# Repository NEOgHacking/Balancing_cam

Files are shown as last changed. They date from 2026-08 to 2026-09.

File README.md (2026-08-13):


# Balancing_cam
This is a side project to improve on the balancing robot with a new smaller esd protected pcb to prevent failures on the board, also to make the board smaller and make room for a second battery pack.
# PCB

This is a small 50x50 PCB made in kicad, it uses the esp32s3 and tmc2209 stepper drivers.
# Specs
Using:
ESP32S3 mini 1
2x TMC2209 stepper drivers
LSM6DS3 IMU
2x battery pack of 2x 18650 cells so in total 4x 18650 cells
connectivity for rc reciever and VTX

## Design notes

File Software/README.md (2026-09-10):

This folder contains the software source files, written for an ESP32 using the Arduino framework. PlatformIO is used as environment, as it is very easy to use, and provides somewhat more advanced functions, compared to the very basic Arduino IDE. 

# Build environment
For setting up PlatformIO, see https://docs.platformio.org/en/latest/ide/vscode.html. 

Clone the repository. I strongly advice to not download the source files as a zip package, but to use Git properly. The code is very experimental, and will be often updated.

Once installed, go to PlatformIO home in the IDE. In there, click "Open Project", and navigate to the location where you cloned the repository. Select the "Software" folder, and then click "Open "Software"". 

Open src/main.cpp. You should now be able to combile (ctrl+alt+B).

# Uploading firmware
For uploading, I strongly prefer OTA, as this works very nice in PlatformIO.  

Beware: when using the A4988 driver, you have to specify a flag. When using any other driver, remove this flag. This is because the A4988 has a different microstepping selection table. 

## Serial port
For the first upload, you'll need to upload via USB / the serial port. In platformio.ini, state the COM port under which the ESP32 module is connected (uncomment the line with an IP address / host name), for example 
upload_port = COM3. 
; upload_port = balancingRobot.local

Hit the upload button. Currently, the auto reset functionality of the ESP32 module doesn't seem to work, see Issue #10. So, once the message "Serial port COMx" appears, press the enable and boot buttons on the module. First release the boot button, then the enable button. You might have to try a few times. Luckily, once succeeded with the serial upload, you can use OTA upload.

## OTA upload
When the ESP32 boots, it's IP address is printed. In platformio.ini, fill in this IP address under upload_port. Or, even better, use the hostname balancingRobot.local. This means you don't have to mess around with IP addresses. Make sure to be connected to the same WiFi network as the ESP32, and hit upload.

*Update*: in the ps3control branch, the ESP32 has insufficient flash memory to store the OTA upload. Hence, it is disabled in this branch. 

## File system
Initially, or when changing the web page files, you need to upload the file system. To do so, open a terminal within the PlatformIO environment, and run:
platformio run --target uploadfs

This will upload all content of the data folder to the ESP32 flash memory (either via the serial port or OTA).

# WiFi connection
After flashing, the ESP32 will start an access point (AP), named balancingRobot. The default key is "turboturbo". Once connected, open the balancingRobot web configuration page (index3.htm). Here, among others, you can change the WiFi options. Under "WiFi configuration", enter the SSID and key of your home network, change the selector from "AP" to "SSID", and click the "set" button, followed by the "reboot" button. If all goes well, the ESP32 will now connect to your home network. 

*Update:* I noticed that in the latest version, the web pages are not correctly loaded, when the ESP32 is running in access point mode. When connected to a known SSID, everything works as it should.
To configure the WiFi settings without a web page, we use the serial interface (115200 baud). 
The command structure is: \
a "w" for wireless related settings, followed by a "s" for SSID, "k" for key, and "m" for WiFi mode (0 = access point, 1 = connect to SSID), followed by the content, followed by a terminating "x". The recipe for connecting to a known SSID is thus:\
wsYOURSSIDx\
wkYOURKEYx\
wm1x\
Restart the ESP32, and it should connect to the known WiFi network ("wrx" will reset the ESP32).\
The serial interface will print information on whether the connection to a known SSID is successful. If the home network cannot be found, the AP will be started.

# Web page editor
hostName.local/edit

User/pass: admin, admin

Be aware though that changes here are not kept on your PC, so make sure to copy and paste everything.

# Plotting signals
hostName.local/plotTest.htm

To be merged into index.htm at some point

For this to work, first load plotTest.htm, then index.htm. This allows to view signals, while simultaneously adjusting parameters. 

# Wifi control
For a slider based web page to control your robot (this will also work in access point mode)

IPaddress/control.htm
hostName.local/control.htm
or, if you connect to the access point of the robot: 192.168.4.1/control.htm

# Bluetooth control
The ps3control branch supports a ps3 controller. This is convenient, as the ESP32 has bluetooth, and no additional hardware is required. 

To be documented, soon hopefully. Very short: use sixaxispairtool to assign the correct MAC address to the PS3 controller. The MAC address is printed over the serial interface, and is also visible in the web interface. 

The ps3control branch doesn't support OTA anymore, as flash space is limited on the ESP32. 

# MQTT dashboard
This branch also supports MQTT-based robot status publishing and command control.

## Robot firmware MQTT behavior
- The ESP32 connects to a WiFi network configured in preferences.
- It publishes status updates every second to `robots/<robotName>/status`.
- Each status message is JSON and includes:
  - `name`
  - `battery`
  - `angle`
  - `state`
- The robot subscribes to:
  - `robots/<robotName>/command`
  - `robots/all/command`
- Supported commands:
  - `stop` — disable control and stop the robot
  - `selfright` / `restart` — trigger a self-right attempt

## Running the PC dashboard
From the `Software` folder, install the Python dependency and start the GUI:

```bash
python3 -m pip install -r requirements.txt
python3 mqtt_dashboard.py
```

The dashboard will:
- discover available robots via `robots/+/status`
- display a status card for each robot
- show battery voltage, angle, and control state
- provide buttons for `Stop` and `Restart` per robot
- provide a global `Stop All Robots` button

## Broker configuration
The default broker is set to `broker.hivemq.com` on port `1883`.

### Using a local broker
For a local MQTT broker, install Mosquitto or another MQTT broker on your network machine.
- On Linux: `sudo apt install mosquitto`
- On macOS: `brew install mosquitto`

Then update the connection target:
- in `src/main.cpp`, change `kMqttBroker` to your broker IP or hostname, for example `"192.168.1.42"`
- in `mqtt_dashboard.py`, either edit `BROKER`/`PORT` or set environment variables:

```bash
export MQTT_BROKER=192.168.1.42
export MQTT_PORT=1883
python3 mqtt_dashboard.py
```

If the broker is running on the same PC as the dashboard, use `localhost` or `127.0.0.1`.

If the broker is on your local network, use the broker's LAN IP address so the ESP32 can reach it.

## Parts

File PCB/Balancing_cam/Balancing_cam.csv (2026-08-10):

Reference | Qty | Value | DNP | Exclude from BOM | Exclude from Board | Footprint | # | LCSC#
C1,C2,C3,C4,C8,C9,C10,C11,C12,C13,C17,C18,C19,C21,C24,C26,C29,C30,C31,C32,C34,C35,C37,C38 | 24 | 100n |  |  |  | Capacitor_SMD:C_0402_1005Metric | 1 | C307331
C5,C14 | 2 | 100μ |  |  |  | Capacitor_SMD:CP_Elec_6.3x5.4 | 2 | C2887272
C6,C15 | 2 | 2u2 |  |  |  | Capacitor_SMD:C_0603_1608Metric | 3 | C57895
C7,C16 | 2 | 22n |  |  |  | Capacitor_SMD:C_0402_1005Metric | 4 | C337699
C20,C25 | 2 | 10u |  |  |  | Capacitor_SMD:C_0603_1608Metric | 5 | C194427
C22 | 1 | 47u |  |  |  | Capacitor_SMD:C_0805_2012Metric | 6 | C19103846
C23,C28 | 2 | 33n |  |  |  | Capacitor_SMD:C_0402_1005Metric | 7 | C472437
C27 | 1 | 100u |  |  |  | Capacitor_SMD:C_1206_3216Metric | 8 | C380356
C33 | 1 | 22u |  |  |  | Capacitor_SMD:C_0603_1608Metric | 9 | C59461
C36 | 1 | 1u |  |  |  | Capacitor_SMD:C_0402_1005Metric | 10 | C14445
C39,C40,C41,C42,C43,C44,C45,C46 | 8 | 1n |  |  |  | Capacitor_SMD:C_0603_1608Metric | 11 | C153291
D1 | 1 | DSK24L |  |  |  | Diode_SMD:D_SOD-123F | 12 | C2939005
D2,D3,D6,D7,D8,D9 | 6 | BAV99W |  |  |  | Package_TO_SOT_SMD:SOT-23 | 13 | C7502727
D4,D5 | 2 | WS2812B-4020 |  |  |  | footprints:WS2812B-4020 | 14 | C965557
F1,F2 | 2 | Fuse |  |  |  | Fuse:Fuseholder_Littelfuse_Nano2_154x | 15 | C108518
J1,J2 | 2 | JST_PH |  |  |  | footprints:JST_PH_S2B-PH-SM4-TB_1x02-1MP_P2.00mm_Horizontal | 16 | C295747
J3 | 1 | USB_C_Receptacle_USB2.0_16P |  |  |  | Connector_USB:USB_C_Receptacle_GCT_USB4105-xx-A_16P_TopMnt_Horizontal | 17 | C165948
J4 | 1 | JST_XH |  |  |  | Connector_JST:JST_XH_B2B-XH-A_1x02_P2.50mm_Vertical | 18 | C158012
J5,J9 | 2 | Conn_01x04 |  |  |  | Connector_PinHeader_2.54mm:PinHeader_1x04_P2.54mm_Vertical | 19 | C7501262
J6,J7 | 2 | Conn_01x04 |  |  |  | Connector_JST:JST_XH_B4B-XH-A_1x04_P2.50mm_Vertical | 20 | C144395
J8 | 1 | Conn_01x03 |  |  |  | Connector_JST:JST_GH_BM03B-GHS-TBT_1x03-1MP_P1.25mm_Vertical | 21 | C160389
L1,L2 | 2 | 2u2 |  |  |  | Inductor_SMD:L_1210_3225Metric | 22 | C3222669
L3,L4,L5,L6,L7,L8,L9,L10,L11,L12,L13,L14 | 12 | BLM18KG121TN1D |  |  |  | Inductor_SMD:L_0603_1608Metric | 23 | C85831
Q1 | 1 | BC817 |  |  |  | Package_TO_SOT_SMD:SOT-23 | 24 | C52801
R1,R2,R3,R4 | 4 | 100m |  |  |  | Resistor_SMD:R_1206_3216Metric | 25 | C309528
R5 | 1 | 52k3 |  |  |  | Resistor_SMD:R_0402_1005Metric | 26 | C2998086
R6,R9,R13,R14,R20 | 5 | 10k |  |  |  | Resistor_SMD:R_0402_1005Metric | 27 | C2906861
R7 | 1 | 14k7 |  |  |  | Resistor_SMD:R_0402_1005Metric | 28 | C2929988
R8 | 1 | 30k9 |  |  |  | Resistor_SMD:R_0402_1005Metric | 29 | C2933086
R10,R11 | 2 | 5.1k |  |  |  | Resistor_SMD:R_0603_1608Metric | 30 | C105580
R12,R21 | 2 | 1k |  |  |  | Resistor_SMD:R_0402_1005Metric | 31 | C2906864
R15,R18,R19 | 3 | 0R |  |  |  | Resistor_SMD:R_0402_1005Metric | 32 | C2906858
R16,R17,R22,R23,R24,R25 | 6 | 100R |  |  |  | Resistor_SMD:R_0603_1608Metric | 33 | C105588
SW1 | 1 | SW_SPDT |  |  |  | footprints:SS12D10G5 | 34 | C7431054
SW2,SW3 | 2 | B3U-1000P |  |  |  | Button_Switch_SMD:SW_SPST_B3U-1000P | 35 | C231329
U1,U2 | 2 | TMC2209-LA |  |  |  | Package_DFN_QFN:VQFN-28-1EP_5x5mm_P0.5mm_EP3.7x3.7mm_ThermalVias | 36 | C2150710
U3,U4 | 2 | TPS62933 |  |  |  | Package_TO_SOT_SMD:SOT-583-8 | 37 | C3200405
U5 | 1 | USBLC6-2P6 |  |  |  | Package_TO_SOT_SMD:SOT-666 | 38 | C15999
U6 | 1 | LSM6DS3 |  |  |  | Package_LGA:LGA-14_3x2.5mm_P0.5mm_LayoutBorder3x4y | 39 | C967633
U7 | 1 | ESP32-S3-MINI-1 |  |  |  | RF_Module:ESP32-S2-MINI-1 | 40 | C2913206

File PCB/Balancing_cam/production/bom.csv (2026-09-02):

Designator | Footprint | Quantity | Value | LCSC Part #
C1_4, C1_3, C1_2, C1, C10_4, C10_3, C10_2, C10, C11_4, C11_3, C11_2, C11, C12_4, C12_3, C12_2, C12, C13_4, C13_3, C13_2, C13, C17_4, C17_3, C17_2, C17, C18_4, C18_3, C18_2, C18, C19_4, C19_3, C19_2, C19, C2_4, C2_3, C2_2, C2, C21_4, C21_3, C21_2, C21, C24_4, C24_3, C24_2, C24, C26_4, C26_3, C26_2, C26, C29_4, C29_3, C29_2, C29, C3_4, C3_3, C3_2, C3, C30_4, C30_3, C30_2, C30, C31_4, C31_3, C31_2, C31, C32_4, C32_3, C32_2, C32, C34_4, C34_3, C34_2, C34, C35_4, C35_3, C35_2, C35, C37_4, C37_3, C37_2, C37, C38_4, C38_3, C38_2, C38, C4_4, C4_3, C4_2, C4, C8_4, C8_3, C8_2, C8, C9_4, C9_3, C9_2, C9 | 0402 | 96 | 100n
C14_4, C14_3, C14_2, C14, C5_4, C5_3, C5_2, C5 | CP_Elec_6.3x5.4 | 8 | 100μ
C15_4, C15_3, C15_2, C15, C6_4, C6_3, C6_2, C6 | 0603 | 8 | 2u2
C16_4, C16_3, C16_2, C16, C7_4, C7_3, C7_2, C7 | 0402 | 8 | 22n
C20_4, C20_3, C20_2, C20, C25_4, C25_3, C25_2, C25 | 0603 | 8 | 10u
C22_4, C22_3, C22_2, C22 | 0805 | 4 | 47u
C23_4, C23_3, C23_2, C23, C28_4, C28_3, C28_2, C28 | 0402 | 8 | 33n
C27_4, C27_3, C27_2, C27 | 1206 | 4 | 100u
C33_4, C33_3, C33_2, C33 | 0603 | 4 | 22u
C36_4, C36_3, C36_2, C36 | 0402 | 4 | 1u
C39_4, C39_3, C39_2, C39, C40_4, C40_3, C40_2, C40, C41_4, C41_3, C41_2, C41, C42_4, C42_3, C42_2, C42, C43_4, C43_3, C43_2, C43, C44_4, C44_3, C44_2, C44, C45_4, C45_3, C45_2, C45, C46_4, C46_3, C46_2, C46 | 0603 | 32 | 1n
D1_4, D1_3, D1_2, D1 | D_SOD-123F | 4 | DSK24L
D2_4, D2_3, D2_2, D2, D3_4, D3_3, D3_2, D3, D6_4, D6_3, D6_2, D6, D7_4, D7_3, D7_2, D7, D8_4, D8_3, D8_2, D8, D9_4, D9_3, D9_2, D9 | SOT-23 | 24 | BAV99W
D4_4, D4_3, D4_2, D4, D5_4, D5_3, D5_2, D5 | WS2812B-4020 | 8 | WS2812B-4020
F1_4, F1_3, F1_2, F1, F2_4, F2_3, F2_2, F2 | Fuseholder_Littelfuse_Nano2_154x | 8 | Fuse
J1_4, J1_3, J1_2, J1, J2_4, J2_3, J2_2, J2 | JST_PH_S2B-PH-SM4-TB_1x02-1MP_P2.00mm_Horizontal | 8 | JST_PH
J3_4, J3_3, J3_2, J3 | USB_C_Receptacle_GCT_USB4105-xx-A_16P_TopMnt_Horizontal | 4 | USB_C_Receptacle_USB2.0_16P
J4_4, J4_3, J4_2, J4 | JST_XH_B2B-XH-A_1x02_P2.50mm_Vertical | 4 | JST_XH
J5_4, J5_3, J5_2, J5, J9_4, J9_3, J9_2, J9 | PinHeader_1x04_P2.54mm_Vertical | 8 | Conn_01x04
J6_4, J6_3, J6_2, J6, J7_4, J7_3, J7_2, J7 | JST_XH_B4B-XH-A_1x04_P2.50mm_Vertical | 8 | Conn_01x04
J8_4, J8_3, J8_2, J8 | JST_GH_BM03B-GHS-TBT_1x03-1MP_P1.25mm_Vertical | 4 | Conn_01x03
L1_4, L1_3, L1_2, L1, L2_4, L2_3, L2_2, L2 | 1210 | 8 | 2u2
L10_4, L10_3, L10_2, L10, L11_4, L11_3, L11_2, L11, L12_4, L12_3, L12_2, L12, L13_4, L13_3, L13_2, L13, L14_4, L14_3, L14_2, L14, L3_4, L3_3, L3_2, L3, L4_4, L4_3, L4_2, L4, L5_4, L5_3, L5_2, L5, L6_4, L6_3, L6_2, L6, L7_4, L7_3, L7_2, L7, L8_4, L8_3, L8_2, L8, L9_4, L9_3, L9_2, L9 | 0603 | 48 | BLM18KG121TN1D
Q1_4, Q1_3, Q1_2, Q1 | SOT-23 | 4 | BC817
R1_4, R1_3, R1_2, R1, R2_4, R2_3, R2_2, R2, R3_4, R3_3, R3_2, R3, R4_4, R4_3, R4_2, R4 | 1206 | 16 | 100m
R10_4, R10_3, R10_2, R10, R11_4, R11_3, R11_2, R11 | 0603 | 8 | 5.1k
R12_4, R12_3, R12_2, R12, R21_4, R21_3, R21_2, R21 | 0402 | 8 | 1k
R13_4, R13_3, R13_2, R13, R14_4, R14_3, R14_2, R14, R20_4, R20_3, R20_2, R20, R6_4, R6_3, R6_2, R6, R9_4, R9_3, R9_2, R9 | 0402 | 20 | 10k
R15_4, R15_3, R15_2, R15, R18_4, R18_3, R18_2, R18, R19_4, R19_3, R19_2, R19 | 0402 | 12 | 0R
R16_4, R16_3, R16_2, R16, R17_4, R17_3, R17_2, R17, R22_4, R22_3, R22_2, R22, R23_4, R23_3, R23_2, R23, R24_4, R24_3, R24_2, R24, R25_4, R25_3, R25_2, R25 | 0603 | 24 | 100R
R5_4, R5_3, R5_2, R5 | 0402 | 4 | 52k3
R7_4, R7_3, R7_2, R7 | 0402 | 4 | 14k7
R8_4, R8_3, R8_2, R8 | 0402 | 4 | 30k9
SW1_4, SW1_3, SW1_2, SW1 | SS12D10G5 | 4 | SW_SPDT
SW2_4, SW2_3, SW2_2, SW2, SW3_4, SW3_3, SW3_2, SW3 | SW_SPST_B3U-1000P | 8 | B3U-1000P
TP1_4, TP1_3, TP1_2, TP1, TP10_4, TP10_3, TP10_2, TP10, TP11_4, TP11_3, TP11_2, TP11, TP12_4, TP12_3, TP12_2, TP12, TP13_4, TP13_3, TP13_2, TP13, TP14_4, TP14_3, TP14_2, TP14, TP15_4, TP15_3, TP15_2, TP15, TP16_4, TP16_3, TP16_2, TP16, TP17_4, TP17_3, TP17_2, TP17, TP18_4, TP18_3, TP18_2, TP18, TP19_4, TP19_3, TP19_2, TP19, TP2_4, TP2_3, TP2_2, TP2, TP21_4, TP21_3, TP21_2, TP21, TP22_4, TP22_3, TP22_2, TP22, TP23_4, TP23_3, TP23_2, TP23, TP3_4, TP3_3, TP3_2, TP3, TP4_4, TP4_3, TP4_2, TP4, TP5_4, TP5_3, TP5_2, TP5, TP6_4, TP6_3, TP6_2, TP6, TP7_4, TP7_3, TP7_2, TP7, TP8_4, TP8_3, TP8_2, TP8, TP9_4, TP9_3, TP9_2, TP9 | TestPoint_Pad_D1.5mm | 88 | TestPoint
U1_4, U1_3, U1_2, U1, U2_4, U2_3, U2_2, U2 | VQFN-28-1EP_5x5mm_P0.5mm_EP3.7x3.7mm_ThermalVias | 8 | TMC2209-LA
U3_4, U3_3, U3_2, U3, U4_4, U4_3, U4_2, U4 | SOT-583-8 | 8 | TPS62933
U5_4, U5_3, U5_2, U5 | SOT-666 | 4 | USBLC6-2P6
U6_4, U6_3, U6_2, U6 | LGA-14_3x2.5mm_P0.5mm_LayoutBorder3x4y | 4 | LSM6DS3
U7_4, U7_3, U7_2, U7 | ESP32-S2-MINI-1 | 4 | ESP32-S3-MINI-1

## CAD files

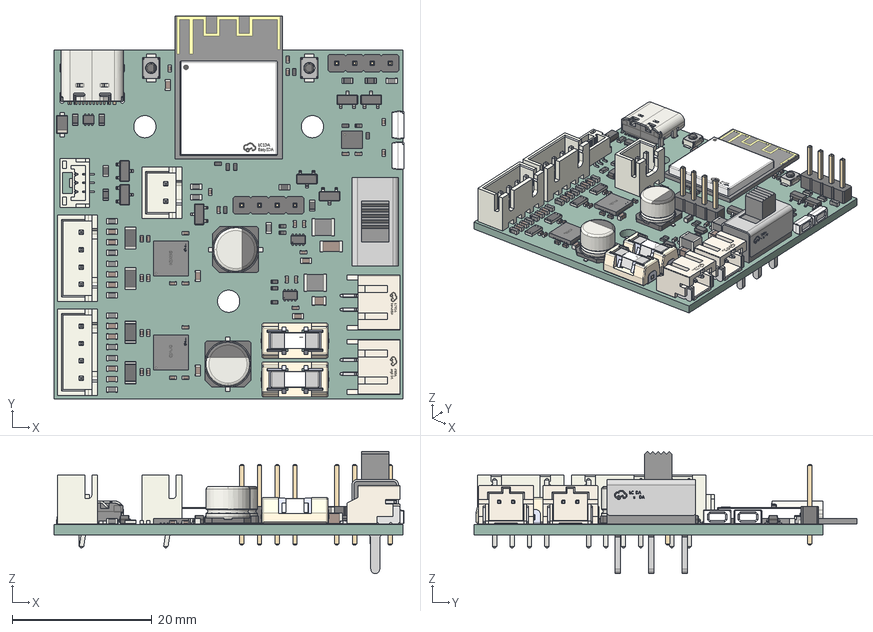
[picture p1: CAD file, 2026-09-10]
PCB/Balancing_cam/Balancing_cam.step
50.1 x 54.9 x 17.5 mm
C_0603_1608Metric x 13
R_1206_3216Metric x 4
CONN-SMD_P2.00_S2B-PH-SM4-TB-LF-SN x 2
C_0402_1005Metric x 29
R_0603_1608Metric x 8
R_0402_1005Metric x 13
D_SOD_123F
L_0603_1608Metric x 12
JST_B4B_XH_A x 2
BULETM-SMD_ESP32-S3-MINI-1-N8
SOT-583-8 x 2
SW_SPST_B3U-1000P x 2
PinHeader_1x04_P254mm_Vertical x 2
SOT-23 x 7
TQFN-28_L5.0-W5.0-H0.8-P0.50 x 2
CP_Elec_63x54 x 2
SW-TH_SHOU-HAN_SS12D10G4
LED-SMD_WS2812B-4020 x 2
L_1210_3225Metric x 2
¼þ1 x 2
¼þ2 x 4
µ艝 x 2
C_1206_3216Metric
USB_C_Receptacle_16P_TopMnt_Horizontal_GCT_USB4105-xx-A
SOT_666
JST_BM03B_GHS_TBT
LGA_14_3x25mm_P05mm_LayoutBorder3x4y
JST_B2B_XH_A
C_0805_2012Metric
Balancing_cam_PCB

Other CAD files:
Balancing_cam.blend

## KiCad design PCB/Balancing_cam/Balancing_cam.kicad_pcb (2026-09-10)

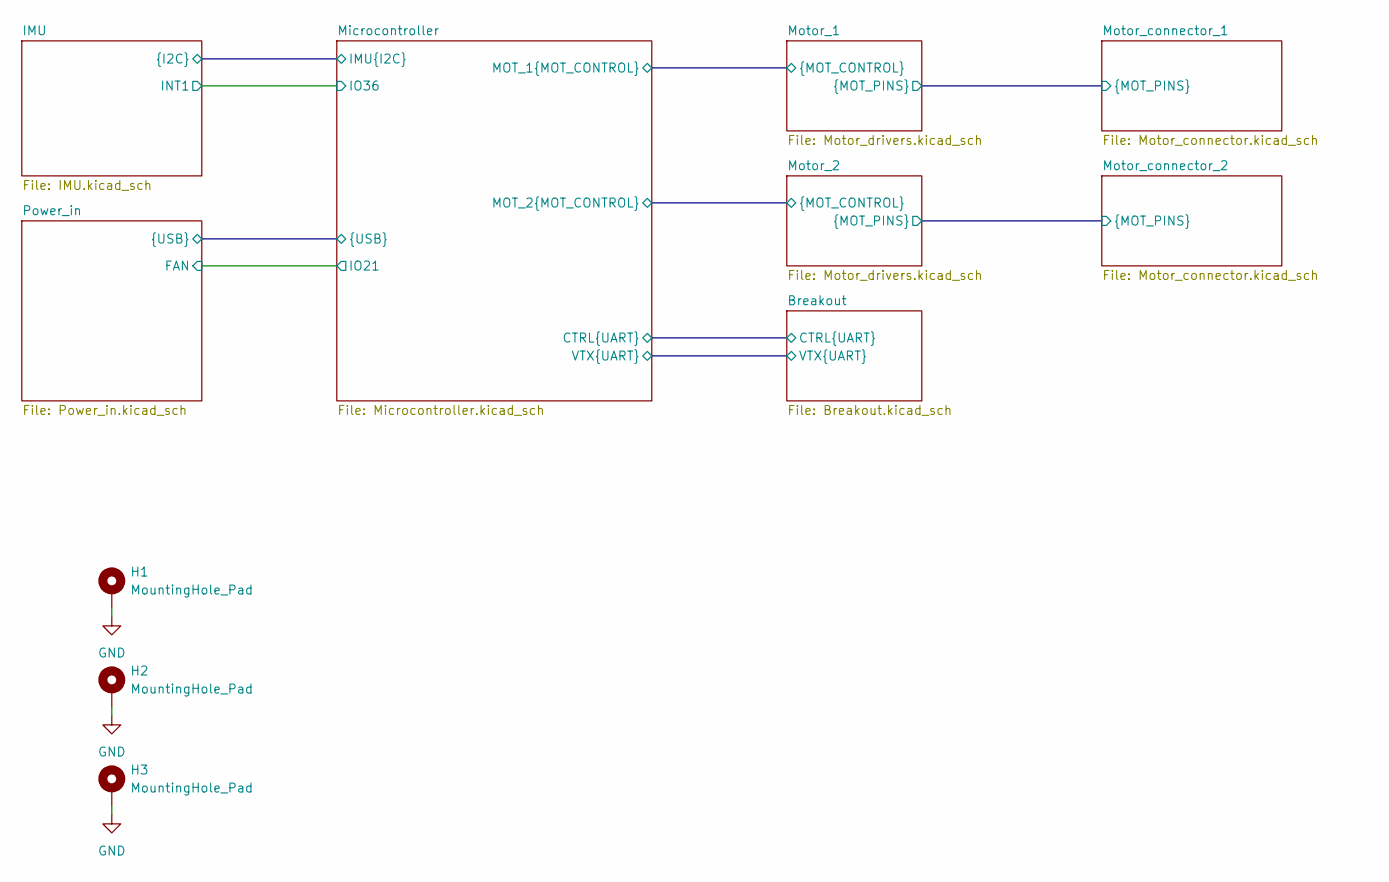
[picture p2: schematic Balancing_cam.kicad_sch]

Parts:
H1, H2, H3: MountingHole_Pad; MountingHole_3.2mm_M3_Pad

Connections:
GND: H1.1 (1_1), H2.1 (1_1), H3.1 (1_1); also elsewhere on the board

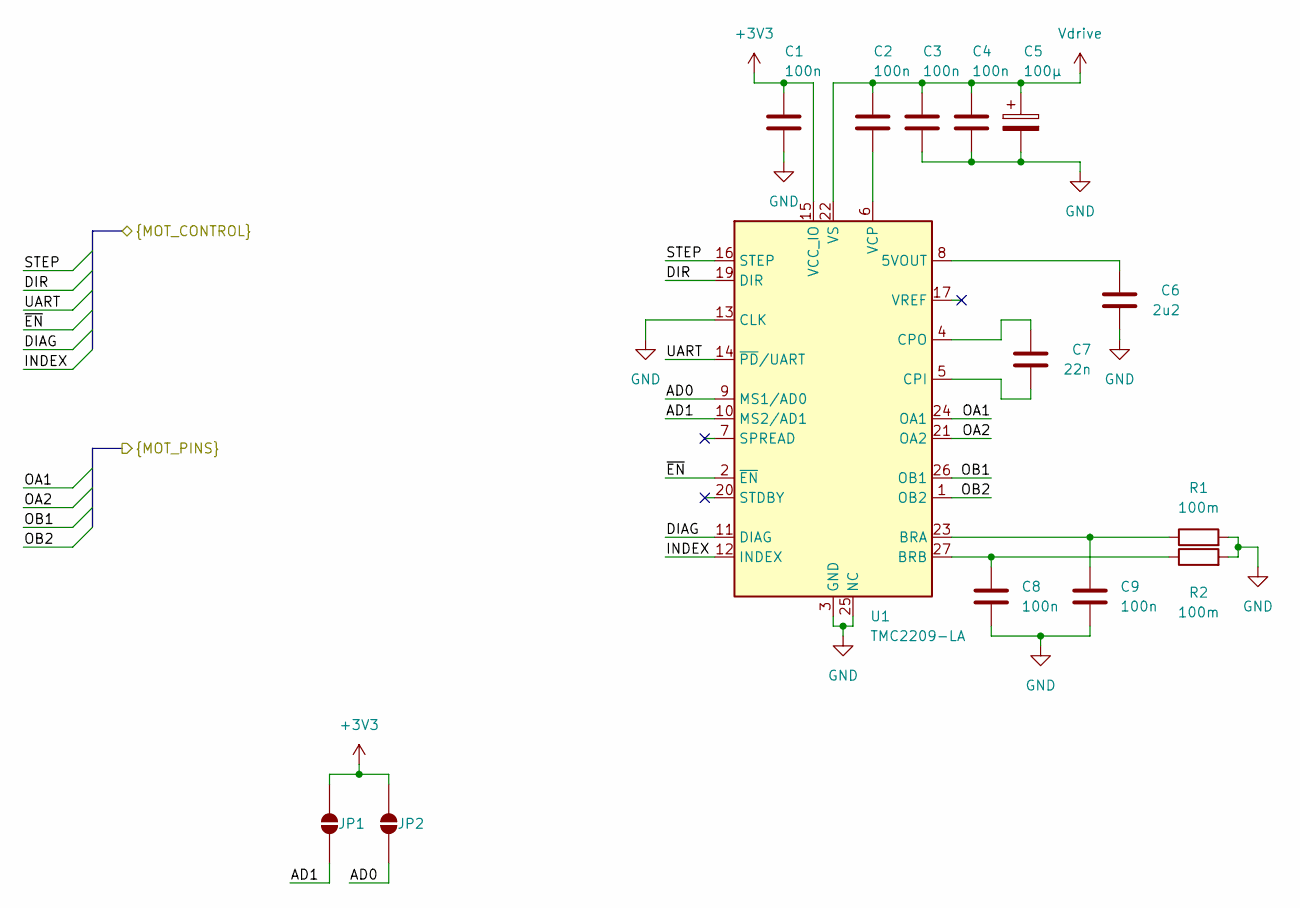
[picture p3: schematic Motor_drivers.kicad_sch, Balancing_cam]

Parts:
C1, C2, C3, C4, C8, C9: 100n; C_0402_1005Metric; LCSC# C307331
C5: 100μ; CP_Elec_6.3x5.4; LCSC# C2887272
C6: 2u2; C_0603_1608Metric; LCSC# C57895
C7: 22n; C_0402_1005Metric; LCSC# C337699
JP1, JP2: SolderJumper_2_Open; SolderJumper-2_P1.3mm_Open_RoundedPad1.0x1.5mm
R1, R2: 100m; R_1206_3216Metric; LCSC# C309528
U1: TMC2209-LA; VQFN-28-1EP_5x5mm_P0.5mm_EP3.7x3.7mm_ThermalVias; LCSC# C2150710

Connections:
+3V3: C1.2, JP1.1 (A), JP2.1 (A), U1.15 (VCC_IO); also elsewhere on the board
/Microcontroller/MOT_1.DIAG: U1.11 (DIAG); also elsewhere on the board
/Microcontroller/MOT_1.DIR: U1.19 (DIR); also elsewhere on the board
/Microcontroller/MOT_1.INDEX: U1.12 (INDEX); also elsewhere on the board
/Microcontroller/MOT_1.STEP: U1.16 (STEP); also elsewhere on the board
/Microcontroller/MOT_1.UART: U1.14 (~PD/UART); also elsewhere on the board
/Microcontroller/MOT_1.~EN: U1.2 (~EN); also elsewhere on the board
/Motor_1/AD0: JP2.2 (B), U1.9 (MS1/AD0)
/Motor_1/AD1: JP1.2 (B), U1.10 (MS2/AD1)
/Motor_1/OA1: U1.24 (OA1); also elsewhere on the board
/Motor_1/OA2: U1.21 (OA2); also elsewhere on the board
/Motor_1/OB1: U1.26 (OB1); also elsewhere on the board
/Motor_1/OB2: U1.1 (OB2); also elsewhere on the board
GND: C1.1, C3.1, C4.1, C5.2, C6.1, C8.2, C9.2, R1.2, R2.2, U1.3 (GND), U1.13 (CLK), U1.18 (GND), U1.25 (NC), U1.29 (GND); also elsewhere on the board
unnamed: C6.2, U1.8 (5VOUT)
unnamed: C9.1, R1.1, U1.23 (BRA)
unnamed: C8.1, R2.1, U1.27 (BRB)
unnamed: C7.1, U1.5 (CPI)
unnamed: C7.2, U1.4 (CPO)
unnamed: C2.1, U1.6 (VCP)
Vdrive: C2.2, C3.2, C4.2, C5.1, U1.22 (VS), U1.28 (VS); also elsewhere on the board

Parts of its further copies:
C10, C11, C12, C13, C17, C18: 100n; C_0402_1005Metric; LCSC# C307331
C14: 100μ; CP_Elec_6.3x5.4; LCSC# C2887272
C15: 2u2; C_0603_1608Metric; LCSC# C57895
C16: 22n; C_0402_1005Metric; LCSC# C337699
JP3, JP4: SolderJumper_2_Open; SolderJumper-2_P1.3mm_Open_RoundedPad1.0x1.5mm
R3, R4: 100m; R_1206_3216Metric; LCSC# C309528
U2: TMC2209-LA; VQFN-28-1EP_5x5mm_P0.5mm_EP3.7x3.7mm_ThermalVias; LCSC# C2150710

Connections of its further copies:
+3V3: C10.2, JP3.1 (A), JP4.1 (A), U2.15 (VCC_IO); also elsewhere on the board
/Microcontroller/MOT_1.UART: U2.14 (~PD/UART); also elsewhere on the board
/Microcontroller/MOT_2.DIAG: U2.11 (DIAG); also elsewhere on the board
/Microcontroller/MOT_2.DIR: U2.19 (DIR); also elsewhere on the board
/Microcontroller/MOT_2.INDEX: U2.12 (INDEX); also elsewhere on the board
/Microcontroller/MOT_2.STEP: U2.16 (STEP); also elsewhere on the board
/Microcontroller/MOT_2.~EN: U2.2 (~EN); also elsewhere on the board
/Motor_2/AD0: JP4.2 (B), U2.9 (MS1/AD0)
/Motor_2/AD1: JP3.2 (B), U2.10 (MS2/AD1)
/Motor_2/OA1: U2.24 (OA1); also elsewhere on the board
/Motor_2/OA2: U2.21 (OA2); also elsewhere on the board
/Motor_2/OB1: U2.26 (OB1); also elsewhere on the board
/Motor_2/OB2: U2.1 (OB2); also elsewhere on the board
GND: C10.1, C12.1, C13.1, C14.2, C15.1, C17.2, C18.2, R3.2, R4.2, U2.3 (GND), U2.13 (CLK), U2.18 (GND), U2.25 (NC), U2.29 (GND); also elsewhere on the board
unnamed: C15.2, U2.8 (5VOUT)
unnamed: C18.1, R3.1, U2.23 (BRA)
unnamed: C17.1, R4.1, U2.27 (BRB)
unnamed: C16.1, U2.5 (CPI)
unnamed: C16.2, U2.4 (CPO)
unnamed: C11.1, U2.6 (VCP)
Vdrive: C11.2, C12.2, C13.2, C14.1, U2.22 (VS), U2.28 (VS); also elsewhere on the board

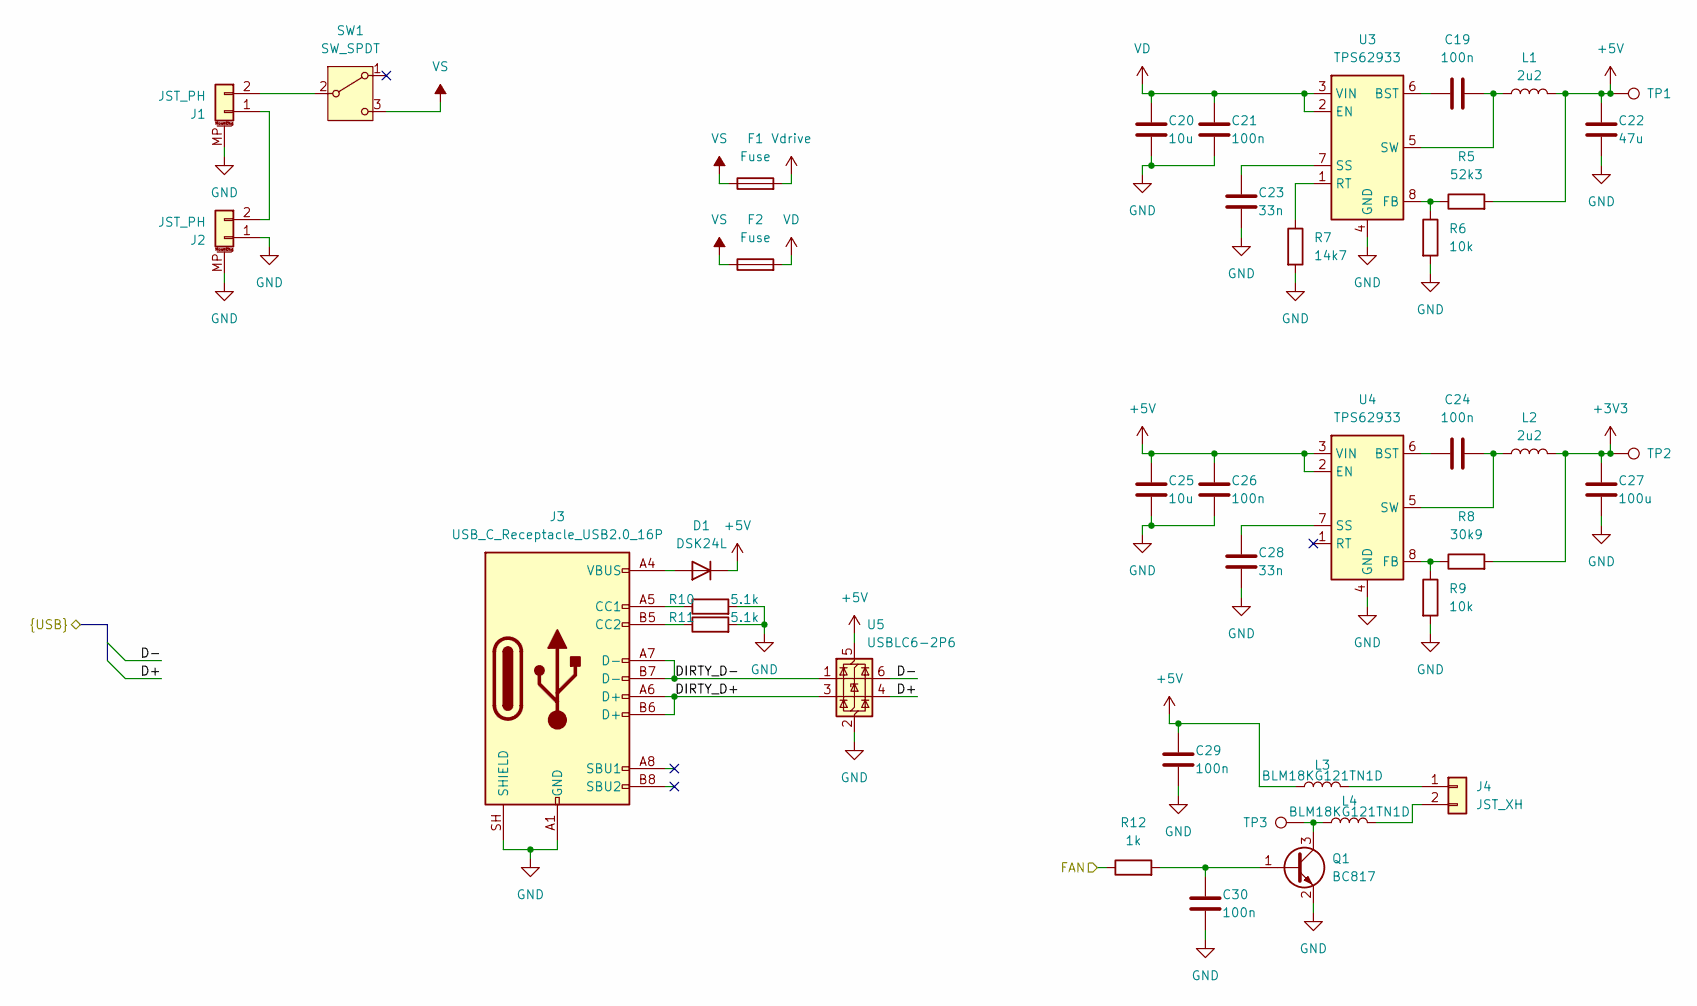
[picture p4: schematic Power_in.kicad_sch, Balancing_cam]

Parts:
C19, C21, C24, C26, C29, C30: 100n; C_0402_1005Metric; LCSC# C307331
C20, C25: 10u; C_0603_1608Metric; LCSC# C194427
C22: 47u; C_0805_2012Metric; LCSC# C19103846
C23, C28: 33n; C_0402_1005Metric; LCSC# C472437
C27: 100u; C_1206_3216Metric; LCSC# C380356
D1: DSK24L; D_SOD-123F; LCSC# C2939005
F1, F2: Fuse; Fuseholder_Littelfuse_Nano2_154x; LCSC# C108518
J1, J2: JST_PH; JST_PH_S2B-PH-SM4-TB_1x02-1MP_P2.00mm_Horizontal; LCSC# C295747
J3: USB_C_Receptacle_USB2.0_16P; USB_C_Receptacle_GCT_USB4105-xx-A_16P_TopMnt_Horizontal; LCSC# C165948
J4: JST_XH; JST_XH_B2B-XH-A_1x02_P2.50mm_Vertical; LCSC# C158012
L1, L2: 2u2; L_1210_3225Metric; LCSC# C3222669
L3, L4: BLM18KG121TN1D; L_0603_1608Metric; LCSC# C85831
Q1: BC817; SOT-23; LCSC# C52801
R5: 52k3; R_0402_1005Metric; LCSC# C2998086
R6, R9: 10k; R_0402_1005Metric; LCSC# C2906861
R7: 14k7; R_0402_1005Metric; LCSC# C2929988
R8: 30k9; R_0402_1005Metric; LCSC# C2933086
R10, R11: 5.1k; R_0603_1608Metric; LCSC# C105580
R12: 1k; R_0402_1005Metric; LCSC# C2906864
SW1: SW_SPDT; SS12D10G5; LCSC# C7431054
TP1, TP2, TP3: TestPoint; TestPoint_Pad_D1.5mm
U3, U4: TPS62933; SOT-583-8; LCSC# C3200405
U5: USBLC6-2P6; SOT-666; LCSC# C15999

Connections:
+3V3: C27.1, L2.2, R8.2, TP2.1 (1_1); also elsewhere on the board
+5V: C22.1, C25.1, C26.1, C29.1, D1.1 (K), L1.2, L3.1, R5.2, TP1.1 (1_1), U4.2 (EN), U4.3 (VIN), U5.5 (VBUS); also elsewhere on the board
/Microcontroller/D+: U5.4 (I/O2); also elsewhere on the board
/Microcontroller/D-: U5.6 (I/O1); also elsewhere on the board
/Microcontroller/IO21: R12.1; also elsewhere on the board
/Power_in/DIRTY_D+: J3.A6 (D+), J3.B6 (D+), U5.3 (I/O2)
/Power_in/DIRTY_D-: J3.A7 (D-), J3.B7 (D-), U5.1 (I/O1)
GND: C20.2, C21.2, C22.2, C23.2, C25.2, C26.2, C27.2, C28.2, C29.2, C30.2, J1.MP (MountPin), J2.1 (Pin_2), J2.MP (MountPin), J3.A1 (GND), J3.A12 (GND), J3.B1 (GND), J3.B12 (GND), J3.SH (SHIELD), Q1.2 (E), R6.2, R7.2, R9.2, R10.2, R11.2, U3.4 (GND), U4.4 (GND), U5.2 (GND); also elsewhere on the board
unnamed: D1.2 (A), J3.A4 (VBUS), J3.A9 (VBUS), J3.B4 (VBUS), J3.B9 (VBUS)
unnamed: J1.2 (Pin_1), SW1.2 (B)
unnamed: J1.1 (Pin_2), J2.2 (Pin_1)
unnamed: J3.A5 (CC1), R10.1
unnamed: J3.B5 (CC2), R11.1
unnamed: J4.1, L3.2
unnamed: J4.2, L4.2
unnamed: C30.1, Q1.1 (B), R12.2
unnamed: L4.1, Q1.3 (C), TP3.1 (1_1)
unnamed: C19.1, U3.6 (BST)
unnamed: R5.1, R6.1, U3.8 (FB)
unnamed: R7.1, U3.1 (RT)
unnamed: C23.1, U3.7 (SS)
unnamed: C19.2, L1.1, U3.5 (SW)
unnamed: C24.1, U4.6 (BST)
unnamed: R8.1, R9.1, U4.8 (FB)
unnamed: C28.1, U4.7 (SS)
unnamed: C24.2, L2.1, U4.5 (SW)
VD: C20.1, C21.1, F2.2, U3.2 (EN), U3.3 (VIN)
VS: F1.1, F2.1, SW1.3 (C)
Vdrive: F1.2; also elsewhere on the board

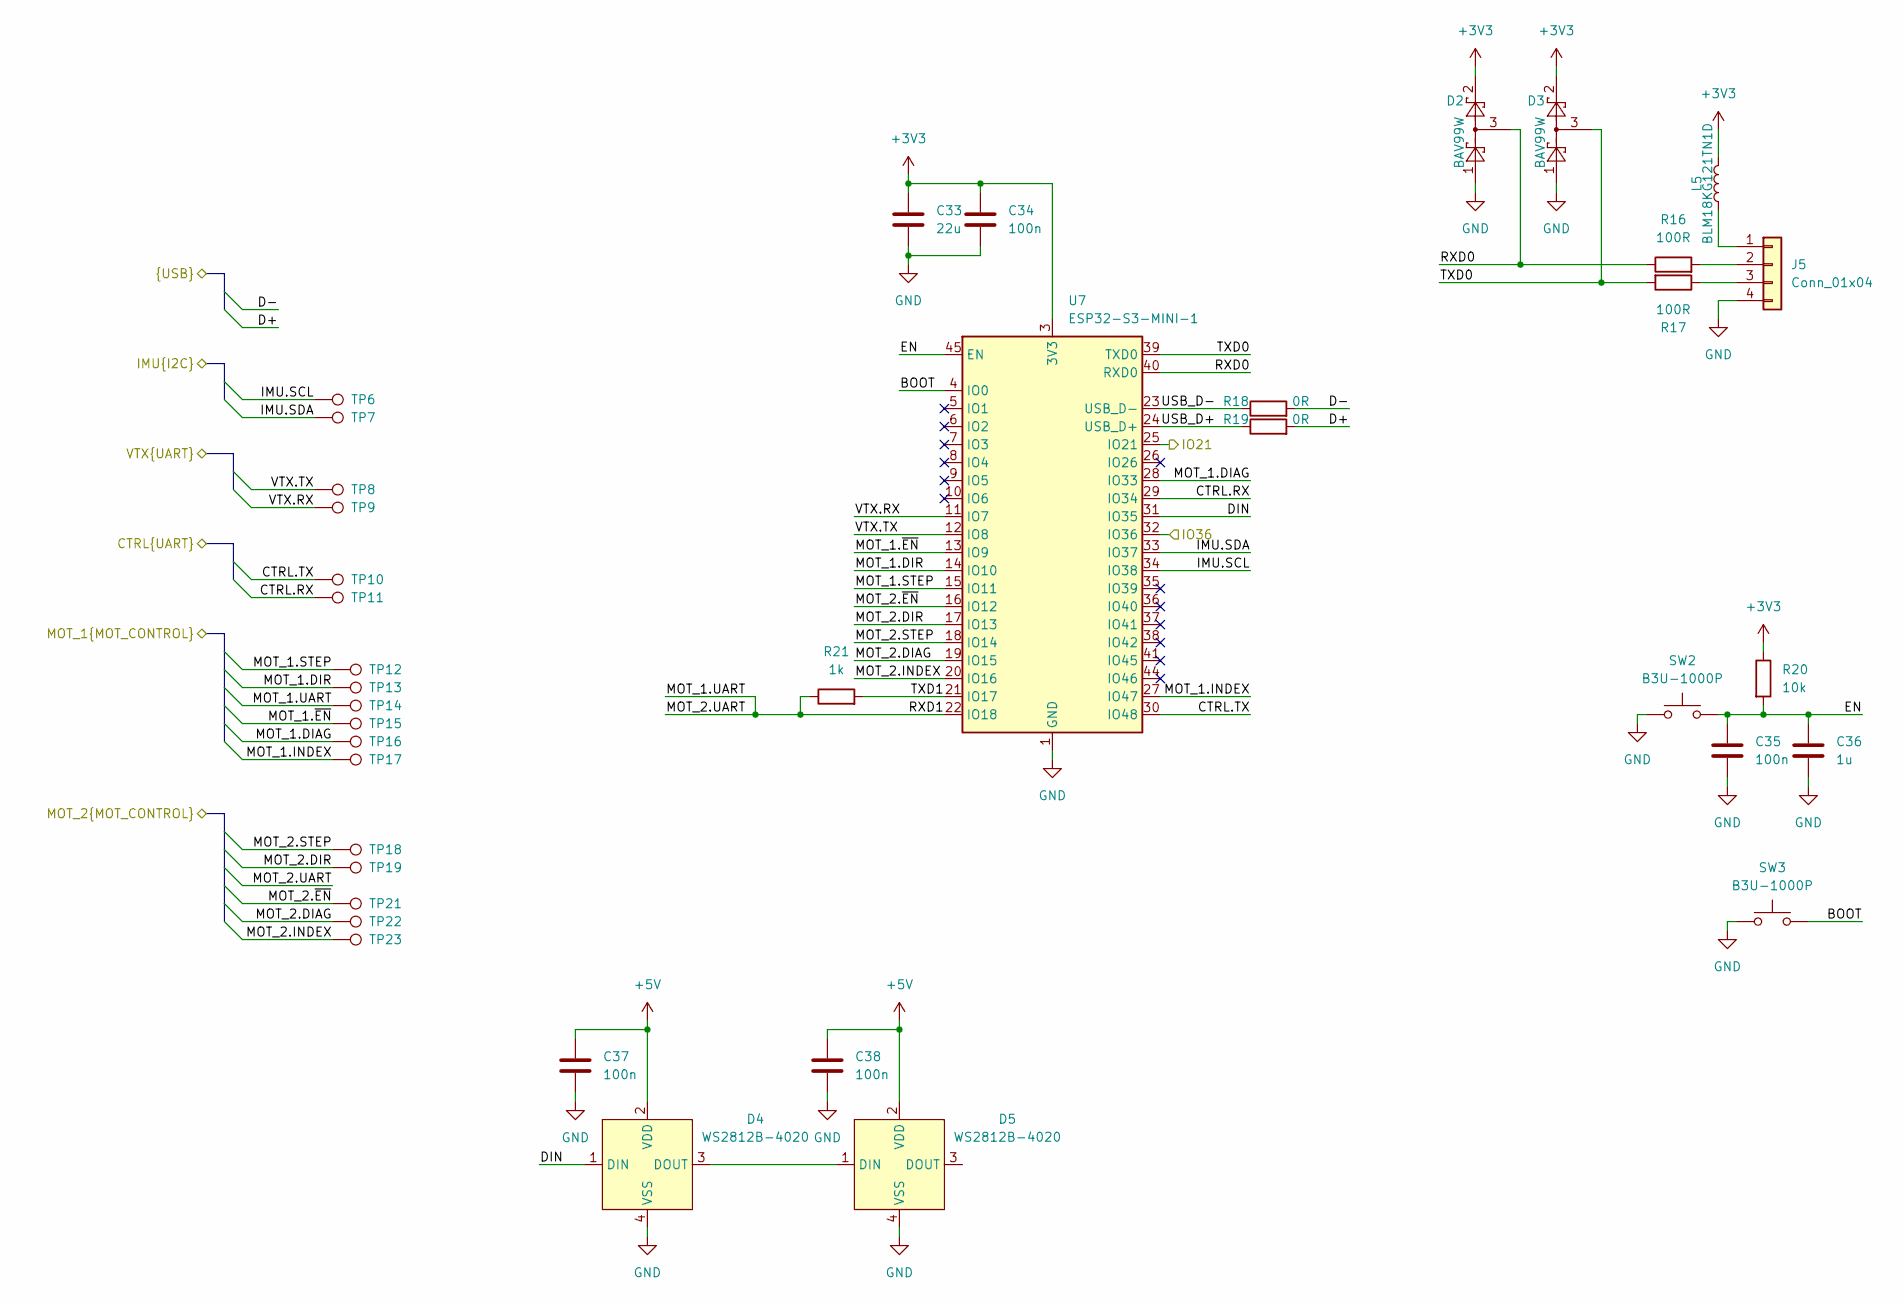
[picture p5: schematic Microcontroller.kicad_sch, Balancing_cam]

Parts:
C33: 22u; C_0603_1608Metric; LCSC# C59461
C34, C35, C37, C38: 100n; C_0402_1005Metric; LCSC# C307331
C36: 1u; C_0402_1005Metric; LCSC# C14445
D2, D3: BAV99W; SOT-23; LCSC# C7502727
D4, D5: WS2812B-4020; LCSC# C965557
J5: Conn_01x04; PinHeader_1x04_P2.54mm_Vertical; LCSC# C7501262
L5: BLM18KG121TN1D; L_0603_1608Metric; LCSC# C85831
R16, R17: 100R; R_0603_1608Metric; LCSC# C105588
R18, R19: 0R; R_0402_1005Metric; LCSC# C2906858
R20: 10k; R_0402_1005Metric; LCSC# C2906861
R21: 1k; R_0402_1005Metric; LCSC# C2906864
SW2, SW3: B3U-1000P; SW_SPST_B3U-1000P; LCSC# C231329
TP6, TP7, TP8, TP9, TP10, TP11, TP12, TP13, TP14, TP15, TP16, TP17, TP18, TP19, TP21, TP22, TP23: TestPoint; TestPoint_Pad_D1.5mm
U7: ESP32-S3-MINI-1; ESP32-S2-MINI-1; LCSC# C2913206

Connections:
+3V3: C33.1, C34.1, D2.2, D3.2, L5.2, R20.1, U7.3 (3V3); also elsewhere on the board
+5V: C37.1, C38.1, D4.2 (VDD), D5.2 (VDD); also elsewhere on the board
/Breakout/CTRL.RX: TP11.1 (1_1), U7.29 (IO34); also elsewhere on the board
/Breakout/CTRL.TX: TP10.1 (1_1), U7.30 (IO48); also elsewhere on the board
/Breakout/VTX.RX: TP9.1 (1_1), U7.11 (IO7); also elsewhere on the board
/Breakout/VTX.TX: TP8.1 (1_1), U7.12 (IO8); also elsewhere on the board
/IMU/INT1: U7.32 (IO36); also elsewhere on the board
/IMU/SCL: TP6.1 (1_1), U7.34 (IO38); also elsewhere on the board
/IMU/SDA: TP7.1 (1_1), U7.33 (IO37); also elsewhere on the board
/Microcontroller/BOOT: SW3.2, U7.4 (IO0)
/Microcontroller/D+: R19.2; also elsewhere on the board
/Microcontroller/D-: R18.2; also elsewhere on the board
/Microcontroller/DIN: D4.1 (DIN), U7.31 (IO35)
/Microcontroller/EN: C35.1, C36.1, R20.2, SW2.2, U7.45 (EN)
/Microcontroller/IO21: U7.25 (IO21); also elsewhere on the board
/Microcontroller/MOT_1.DIAG: TP16.1 (1_1), U7.28 (IO33); also elsewhere on the board
/Microcontroller/MOT_1.DIR: TP13.1 (1_1), U7.14 (IO10); also elsewhere on the board
/Microcontroller/MOT_1.INDEX: TP17.1 (1_1), U7.27 (IO47); also elsewhere on the board
/Microcontroller/MOT_1.STEP: TP12.1 (1_1), U7.15 (IO11); also elsewhere on the board
/Microcontroller/MOT_1.UART: R21.1, TP14.1 (1_1), U7.22 (IO18); also elsewhere on the board
/Microcontroller/MOT_1.~EN: TP15.1 (1_1), U7.13 (IO9); also elsewhere on the board
/Microcontroller/MOT_2.DIAG: TP22.1 (1_1), U7.19 (IO15); also elsewhere on the board
/Microcontroller/MOT_2.DIR: TP19.1 (1_1), U7.17 (IO13); also elsewhere on the board
/Microcontroller/MOT_2.INDEX: TP23.1 (1_1), U7.20 (IO16); also elsewhere on the board
/Microcontroller/MOT_2.STEP: TP18.1 (1_1), U7.18 (IO14); also elsewhere on the board
/Microcontroller/MOT_2.~EN: TP21.1 (1_1), U7.16 (IO12); also elsewhere on the board
/Microcontroller/RXD0: D2.3, R16.1, U7.40 (RXD0)
/Microcontroller/TXD0: D3.3, R17.2, U7.39 (TXD0)
/Microcontroller/TXD1: R21.2, U7.21 (IO17)
/Microcontroller/USB_D+: R19.1, U7.24 (USB_D+)
/Microcontroller/USB_D-: R18.1, U7.23 (USB_D-)
GND: C33.2, C34.2, C35.2, C36.2, C37.2, C38.2, D2.1, D3.1, D4.4 (VSS), D5.4 (VSS), J5.4, SW2.1, SW3.1, U7.1 (GND), U7.2 (GND), U7.42 (GND), U7.43 (GND), U7.46 (GND), U7.47 (GND), U7.48 (GND), U7.49 (GND), U7.50 (GND), U7.51 (GND), U7.52 (GND), U7.53 (GND), U7.54 (GND), U7.55 (GND), U7.56 (GND), U7.57 (GND), U7.58 (GND), U7.59 (GND), U7.60 (GND), U7.61 (GND), U7.62 (GND), U7.63 (GND), U7.64 (GND), U7.65 (GND); also elsewhere on the board
unnamed: D4.3 (DOUT), D5.1 (DIN)
unnamed: J5.1, L5.1
unnamed: J5.2, R16.2
unnamed: J5.3, R17.1

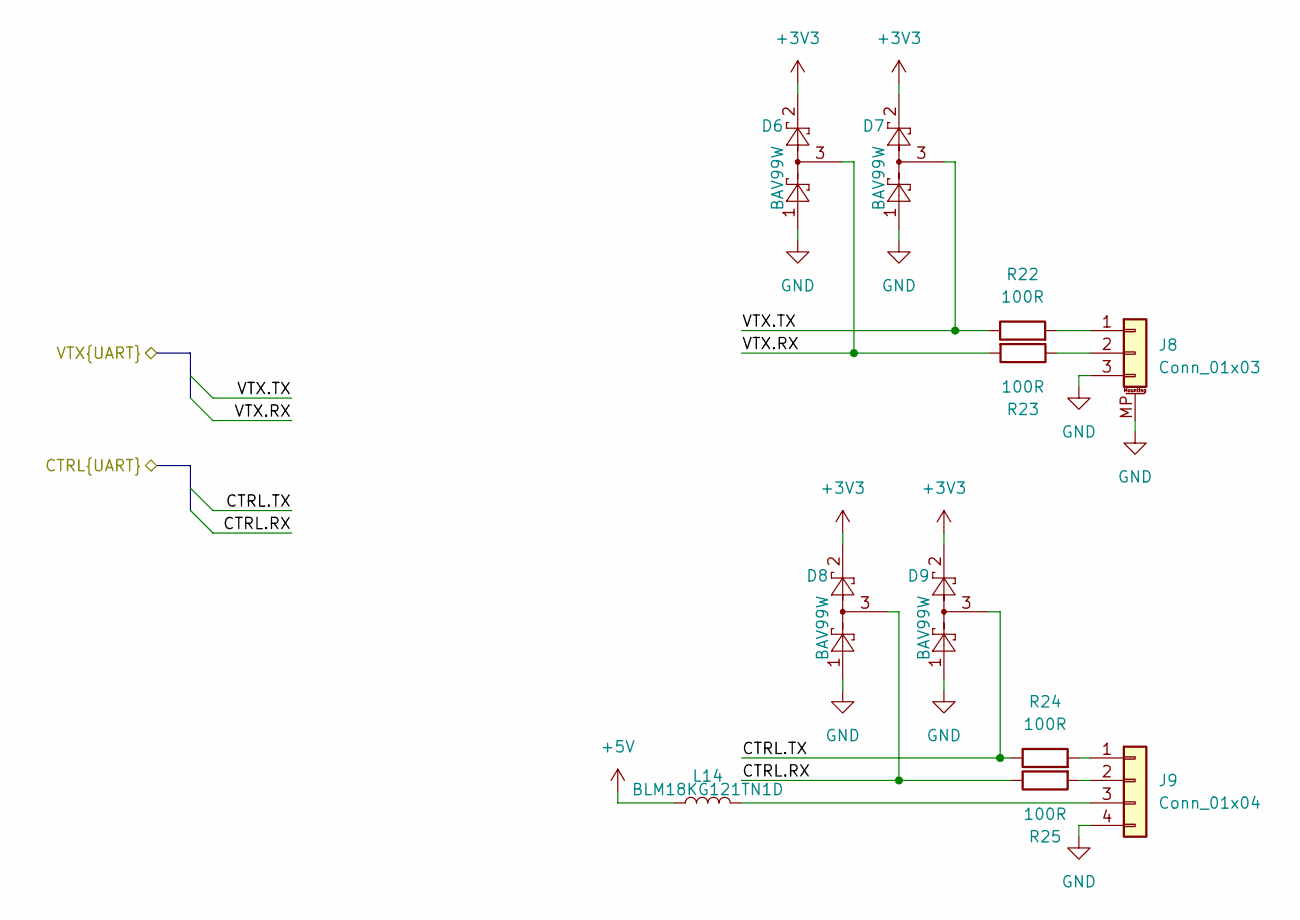
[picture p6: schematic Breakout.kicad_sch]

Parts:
D6, D7, D8, D9: BAV99W; SOT-23; LCSC# C7502727
J8: Conn_01x03; JST_GH_BM03B-GHS-TBT_1x03-1MP_P1.25mm_Vertical; LCSC# C160389
J9: Conn_01x04; PinHeader_1x04_P2.54mm_Vertical; LCSC# C7501262
L14: BLM18KG121TN1D; L_0603_1608Metric; LCSC# C85831
R22, R23, R24, R25: 100R; R_0603_1608Metric; LCSC# C105588

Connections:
+3V3: D6.2, D7.2, D8.2, D9.2; also elsewhere on the board
+5V: L14.1; also elsewhere on the board
/Breakout/CTRL.RX: D8.3, R25.1; also elsewhere on the board
/Breakout/CTRL.TX: D9.3, R24.1; also elsewhere on the board
/Breakout/VTX.RX: D6.3, R23.2; also elsewhere on the board
/Breakout/VTX.TX: D7.3, R22.1; also elsewhere on the board
GND: D6.1, D7.1, D8.1, D9.1, J8.3, J8.MP (MountPin), J9.4; also elsewhere on the board
unnamed: J8.1, R22.2
unnamed: J8.2, R23.1
unnamed: J9.1, R24.2
unnamed: J9.2, R25.2
unnamed: J9.3, L14.2

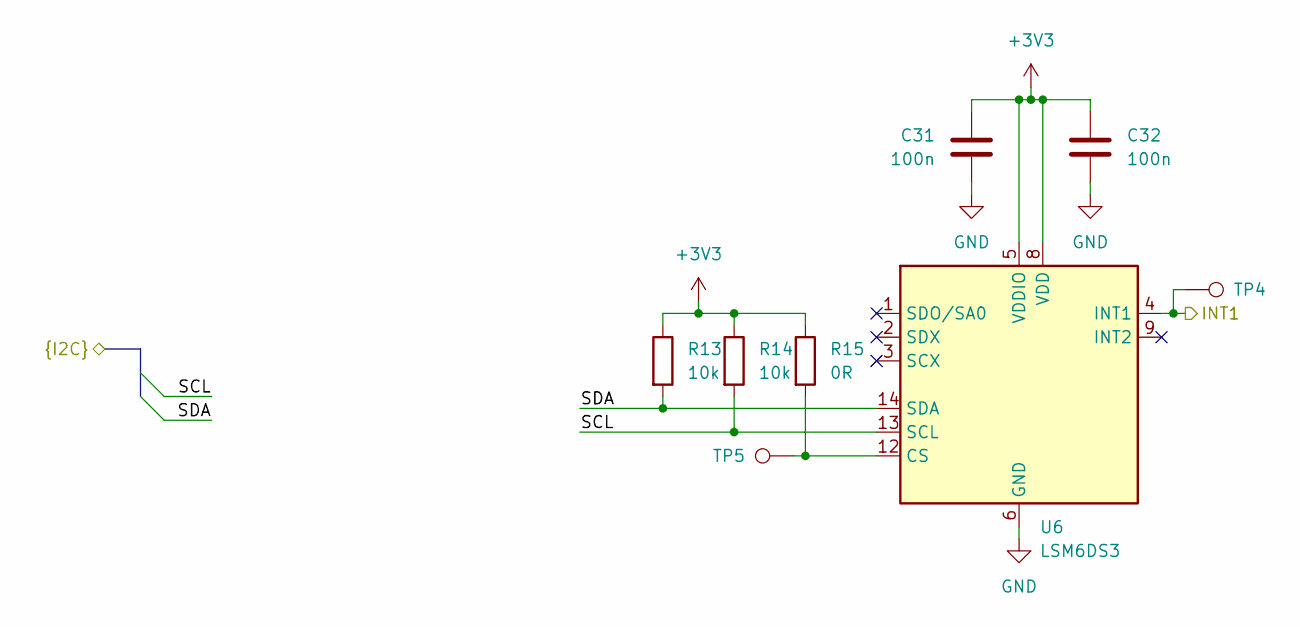
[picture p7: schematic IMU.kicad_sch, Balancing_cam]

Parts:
C31, C32: 100n; C_0402_1005Metric; LCSC# C307331
R13, R14: 10k; R_0402_1005Metric; LCSC# C2906861
R15: 0R; R_0402_1005Metric; LCSC# C2906858
TP4, TP5: TestPoint; TestPoint_Pad_D1.5mm
U6: LSM6DS3; LGA-14_3x2.5mm_P0.5mm_LayoutBorder3x4y; LCSC# C967633

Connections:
+3V3: C31.1, C32.1, R13.1, R14.1, R15.1, U6.5 (VDDIO), U6.8 (VDD); also elsewhere on the board
/IMU/INT1: TP4.1 (1_1), U6.4 (INT1); also elsewhere on the board
/IMU/SCL: R14.2, U6.13 (SCL); also elsewhere on the board
/IMU/SDA: R13.2, U6.14 (SDA); also elsewhere on the board
GND: C31.2, C32.2, U6.6 (GND), U6.7 (GND); also elsewhere on the board
unnamed: R15.2, TP5.1 (1_1), U6.12 (CS)

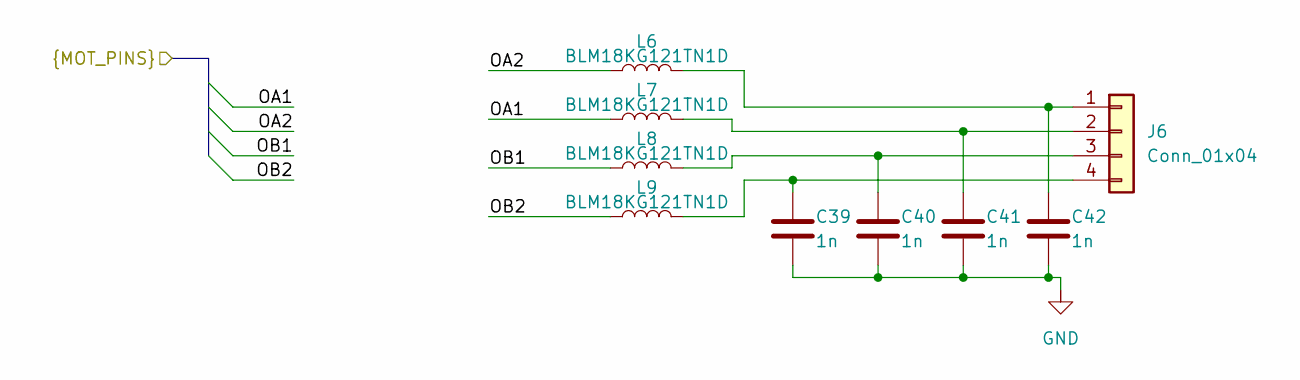
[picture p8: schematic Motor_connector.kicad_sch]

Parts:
C39, C40, C41, C42: 1n; C_0603_1608Metric; LCSC# C153291
J6: Conn_01x04; JST_XH_B4B-XH-A_1x04_P2.50mm_Vertical; LCSC# C144395
L6, L7, L8, L9: BLM18KG121TN1D; L_0603_1608Metric; LCSC# C85831

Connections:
/Motor_1/OA1: L7.1; also elsewhere on the board
/Motor_1/OA2: L6.1; also elsewhere on the board
/Motor_1/OB1: L8.1; also elsewhere on the board
/Motor_1/OB2: L9.1; also elsewhere on the board
GND: C39.2, C40.2, C41.2, C42.2; also elsewhere on the board
unnamed: C42.1, J6.1, L6.2
unnamed: C41.1, J6.2, L7.2
unnamed: C40.1, J6.3, L8.2
unnamed: C39.1, J6.4, L9.2

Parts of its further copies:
C43, C44, C45, C46: 1n; C_0603_1608Metric; LCSC# C153291
J7: Conn_01x04; JST_XH_B4B-XH-A_1x04_P2.50mm_Vertical; LCSC# C144395
L10, L11, L12, L13: BLM18KG121TN1D; L_0603_1608Metric; LCSC# C85831

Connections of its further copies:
/Motor_2/OA1: L11.1; also elsewhere on the board
/Motor_2/OA2: L10.1; also elsewhere on the board
/Motor_2/OB1: L12.1; also elsewhere on the board
/Motor_2/OB2: L13.1; also elsewhere on the board
GND: C43.2, C44.2, C45.2, C46.2; also elsewhere on the board
unnamed: C46.1, J7.1, L10.2
unnamed: C45.1, J7.2, L11.2
unnamed: C44.1, J7.3, L12.2
unnamed: C43.1, J7.4, L13.2

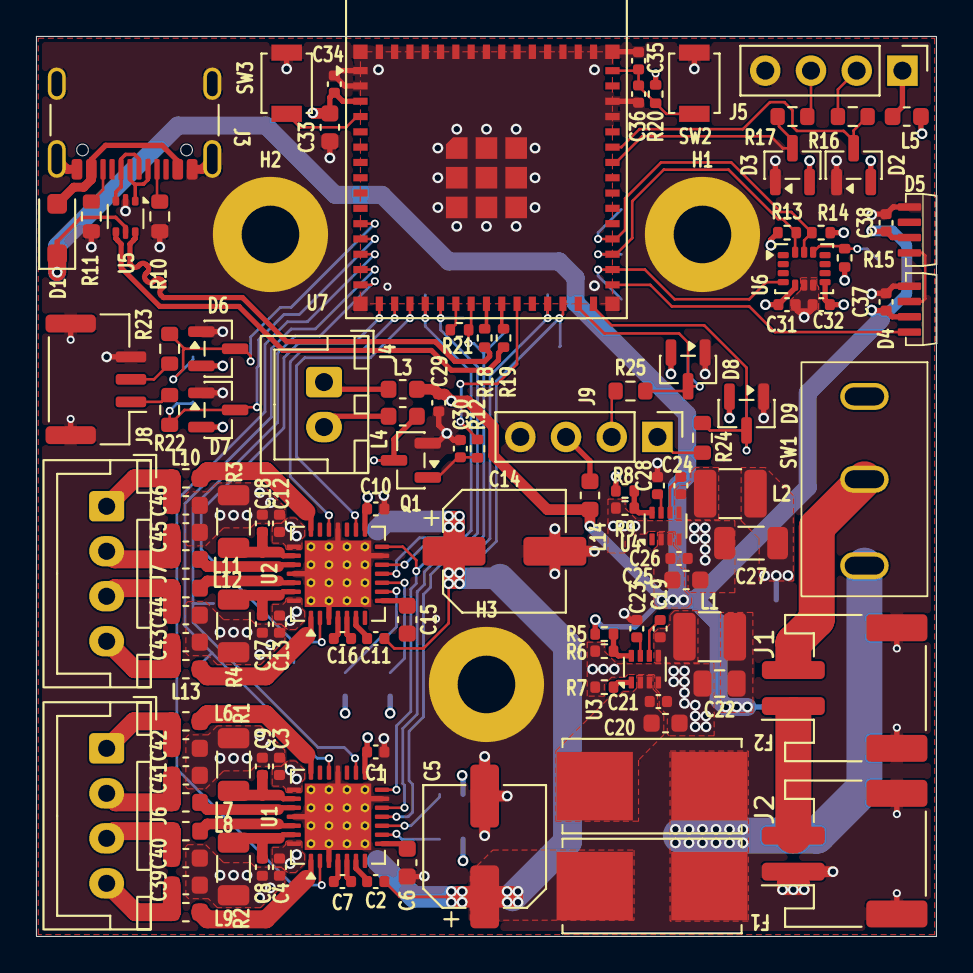
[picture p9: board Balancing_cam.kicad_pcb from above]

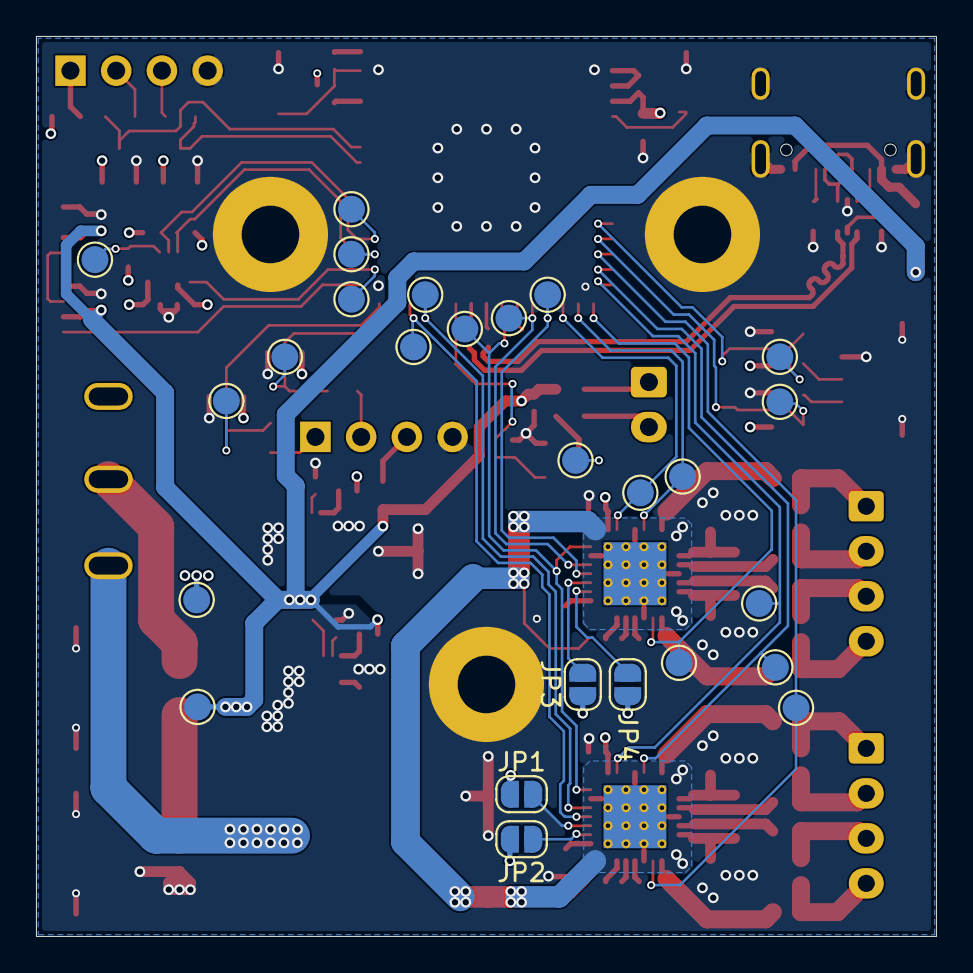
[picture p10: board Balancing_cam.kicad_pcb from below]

Board: 4 copper layers, 50.0 x 50.0 mm, 145 parts (26 on the bottom side), 97 nets.

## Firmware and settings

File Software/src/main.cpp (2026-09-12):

/*
A high speed balancing robot, running on an ESP32.

Wouter Klop
wouter@elexperiment.nl
For updates, see elexperiment.nl

Use at your own risk. This code is far from stable.

This work is licensed under the Creative Commons Attribution-ShareAlike 4.0 International License.
To view a copy of this license, visit http://creativecommons.org/licenses/by-sa/4.0/
This basically means: if you use my code, acknowledge it.
Also, you have to publish all modifications.
*/

#define esp32_s3

#include <Arduino.h>
#include <Wire.h>
#include <FlySkyIBus.h>
#include <WiFi.h>
#include <ESPmDNS.h>
#include <WiFiUdp.h>
#include <ArduinoOTA.h>
#include <Streaming.h>
#include <MPU6050.h>
#include <PID.h>
#include <AsyncTCP.h>
#include <PubSubClient.h>
#include <ESPAsyncWebServer.h>
#include <WebSocketsServer.h>
#include <FS.h>
#include <SPIFFS.h>
#include <SPIFFSEditor.h>
#include <fastStepper.h>
#include <Preferences.h>
#ifdef esp32_s3
#include <esp_now.h>
#include <TMC2209.h>
#include <LSM6DS3TRC.h>
#endif
#if defined(INPUT_PS3) && !defined(esp32_s3)
#include <Ps3Controller.h>
#endif
#include "driver/adc.h"
#include "esp_adc_cal.h"

// #define NEWPCB
// #define INPUT_PPM
// #define INPUT_IBUS
// #define INPUT_PS3

// Pin definitions
#ifdef esp32_s3
constexpr uint8_t kPinMotorEnable = 27;
constexpr uint8_t kPinLed = 34;
constexpr uint8_t kPinLedLeft = 4;
constexpr uint8_t kPinLedRight = 5;
constexpr uint8_t kPinMotorCurrent = 39;
constexpr uint8_t kPinFan = 21;
constexpr adc1_channel_t kBatteryAdcChannel = ADC1_CHANNEL_6;
constexpr long kTmcSerialBaudRate = 115200;
constexpr long kTmcSerialBaudRateStep = 115200;
constexpr int kTmcRunCurrent = 10;
constexpr int kTmcRxPin = 18;
constexpr int kTmcTxPin = 17;
constexpr int kTmcEnablePinLeft = 9;
constexpr int kTmcEnablePinRight = 12;
constexpr int kTmcStepPinLeft = 11;
constexpr int kTmcStepPinRight = 14;
constexpr int kTmcDirPinLeft = 10;
constexpr int kTmcDirPinRight = 13;
constexpr uint8_t kImuSdaPin = 37;
constexpr uint8_t kImuSclPin = 38;
#else
constexpr uint8_t kPinMotorEnable = 27;
constexpr uint8_t kPinMicroStep1 = 14;
constexpr uint8_t kPinMicroStep2 = 12;
constexpr uint8_t kPinMicroStep3 = 13;
constexpr uint8_t kPinLed = 32;
constexpr uint8_t kPinLedLeft = 33;
constexpr uint8_t kPinLedRight = 26;
constexpr uint8_t kPinMotorCurrent = 25;
constexpr adc1_channel_t kBatteryAdcChannel = ADC1_CHANNEL_6;
#endif

// Webserver constants
constexpr char kHttpUsername[] = "admin";
constexpr char kHttpPassword[] = "admin";
constexpr char kDefaultRobotName[] = "balancingrobot";
constexpr char kWifiApPassword[] = "turboturbo";
constexpr bool kFormatSPIFFSIfFailed = true;
constexpr size_t kRobotNameBufferSize = 63;
constexpr size_t kBtAddressBufferSize = 20;
constexpr uint32_t kPreferenceVersion = 1;
constexpr uint32_t kControlPeriodUs = 5000;
constexpr float kAngleErrorIntegralThreshold = 30.0f;
constexpr float kAngleErrorIntegralThresholdDuringSelfRight = kAngleErrorIntegralThreshold * 3.0f;
constexpr float kAngleEnableThreshold = 5.0f;
constexpr float kAngleDisableThreshold = 70.0f;
constexpr float kBatteryVoltageFilter = 0.99f;
constexpr float kBatteryVoltageScale = (100.0f + 3.3f) / 3.3f;
constexpr float kGyroSensitivity = 65.5f;
constexpr char kMqttBroker[] = "172.16.56.100";
constexpr uint16_t kMqttPort = 1883;
constexpr uint32_t kMqttPublishIntervalMs = 1000;
constexpr char kMqttAllCommandTopic[] = "robots/all/command";
constexpr size_t kMqttTopicBufferSize = 128;

enum ControlMode : uint8_t {
  CONTROL_ANGLE_ONLY = 0,
  CONTROL_ANGLE_POSITION = 1,
  CONTROL_ANGLE_SPEED = 2,
};

struct PlotSettings {
  bool enable = false;
  uint8_t prescaler = 4;
};

typedef union {
  uint8_t arr[6];
  struct {
    uint8_t grp;
    uint8_t cmd;
    union {
      float val;
      uint8_t valU8[4];
    } __attribute__((packed));
  } __attribute__((packed));
} cmd;

typedef union {
  struct {
    float val;
    uint8_t cmd;
    uint8_t checksum;
  } __attribute__((packed));
  uint8_t array[6];
} command;

struct RemoteControl {
  float speed = 0;
  float steer = 0;
  float speedGain = 0.15f;
  float steerGain = 0.25f;
  float speedOffset = 0.0f;
  bool selfRight = false;
  bool disableControl = false;
  bool overrideControl = false;
};

struct ControlState {
  bool active = false;
  bool overrideActive = false;
  bool selfRightActive = false;
  bool disableControlActive = false;
  float filteredSpeed = 0;
  float filteredSteer = 0;
  float averageMotorSpeed = 0;
  float angleErrorIntegral = 0;
  float batteryVoltage = 0;
  uint32_t lastInputMs = 0;
  uint32_t lastBatteryReportMs = 0;
  uint8_t plotTicker = 0;
};

// Global state
PlotSettings plot;
RemoteControl remoteControl;
ControlState controlState;

AsyncWebServer httpServer(80);
WebSocketsServer wsServer(81);
Preferences preferences;
WiFiClient mqttWifiClient;
PubSubClient mqttClient(mqttWifiClient);
char mqttStatusTopic[kMqttTopicBufferSize];
char mqttCommandTopic[kMqttTopicBufferSize];
uint32_t lastMqttPublishMs = 0;

void motLeftTimerFunction();
void motRightTimerFunction();
#if defined(INPUT_PS3) && !defined(esp32_s3)
void onPs3Notify();
void onPs3Connect();
void onPs3Disconnect();
#endif

#ifdef esp32_s3
constexpr uint32_t kEspNowControllerMagic = 0x42524F54;
constexpr uint8_t kEspNowControllerVersion = 1;
constexpr uint32_t kEspNowControllerTimeoutMs = 500;

enum EspNowControllerButton : uint16_t {
  ESP_NOW_BUTTON_DOWN = 1 << 0,
  ESP_NOW_BUTTON_LEFT = 1 << 1,
  ESP_NOW_BUTTON_UP = 1 << 2,
  ESP_NOW_BUTTON_RIGHT = 1 << 3,
  ESP_NOW_BUTTON_CIRCLE = 1 << 4,
  ESP_NOW_BUTTON_CROSS = 1 << 5,
  ESP_NOW_BUTTON_SQUARE = 1 << 6,
  ESP_NOW_BUTTON_R1 = 1 << 7,
  ESP_NOW_BUTTON_R2 = 1 << 8,
};

struct EspNowControllerPacket {
  uint32_t magic;
  uint8_t version;
  bool connected;
  int8_t leftStickY;
  int8_t rightStickX;
  uint16_t buttons;
} __attribute__((packed));

volatile EspNowControllerPacket espNowControllerPacket = {};
volatile uint32_t espNowLastPacketMs = 0;
volatile bool espNowPacketReceived = false;

void onEspNowDataReceived(const uint8_t* macAddress, const uint8_t* data, int length) {
  if (length != sizeof(EspNowControllerPacket)) {
    return;
  }

  EspNowControllerPacket packet;
  memcpy(&packet, data, sizeof(packet));
  if (packet.magic != kEspNowControllerMagic || packet.version != kEspNowControllerVersion) {
    return;
  }

  memcpy((void*)&espNowControllerPacket, &packet, sizeof(packet));
  espNowLastPacketMs = millis();
  espNowPacketReceived = true;
}
#endif

uint8_t microStep = 16;
uint8_t motorCurrent = 150;
float maxStepSpeed = 1500.0f;

// Preference-backed defaults for PID angle controller (can be overridden from EEPROM)
float pref_pid1_p = 0.65f;
float pref_pid1_i = 1.0f;
float pref_pid1_d = 0.075f;
float pref_pid1_m = 15.0f;

PID pidAngle(cPID, kControlPeriodUs / 1000000.0f, 12.0f, -12.0f);
PID pidPos(cPD, kControlPeriodUs / 1000000.0f, 35.0f, -35.0f);
PID pidSpeed(cP, kControlPeriodUs / 1000000.0f, 35.0f, -35.0f);
ControlMode controlMode = CONTROL_ANGLE_POSITION;

#ifdef esp32_s3
LSM6DS3 imu(I2C_MODE, 0x6B);
bool imuReady = false;
#else
MPU6050 imu;
#endif
int16_t gyroOffset[3] = {0, 0, 0};
float accAngle = 0;
float filterAngle = 0;
float angleOffset = 2.0f;
float gyroFilterConstant = 0.996f;
float gyroGain = 1.0f;

bool noiseSourceEnable = false;
float noiseSourceAmplitude = 1.0f;
float ayg = 0.0f;
float azg = 0.0f;
float rxg = 0.0f;
float speedFactor = 0.7f;
float steerFactor = 1.0f;
float speedFilterConstant = 0.9f;
float steerFilterConstant = 0.9f;

char robotName[kRobotNameBufferSize] = {0};
char BTaddress[kBtAddressBufferSize] = {0};

esp_adc_cal_characteristics_t adcChars;

portMUX_TYPE timerMux = portMUX_INITIALIZER_UNLOCKED;

extern fastStepper motLeft;
extern fastStepper motRight;

void IRAM_ATTR motLeftTimerFunction() {
  portENTER_CRITICAL_ISR(&timerMux);
  motLeft.timerFunction();
  portEXIT_CRITICAL_ISR(&timerMux);
}

void IRAM_ATTR motRightTimerFunction() {
  portENTER_CRITICAL_ISR(&timerMux);
  motRight.timerFunction();
  portEXIT_CRITICAL_ISR(&timerMux);
}

#ifdef esp32_s3
HardwareSerial& tmcSerialStream = Serial1;
TMC2209 stepperDriverLeft;
TMC2209 stepperDriverRight;

fastStepper motLeft(11, 10, 0, motLeftTimerFunction);
fastStepper motRight(14, 13, 1, motRightTimerFunction);
#else
fastStepper motLeft(5, 4, 0, motLeftTimerFunction);
#ifdef NEWPCB
fastStepper motRight(2, 15, 1, motRightTimerFunction);
#else
fastStepper motRight(2, 15, 1, motRightTimerFunction);
#endif
#endif

void echoChipInformation();
void initHardware();
void initStorage();
void initImu();
void initNetwork();
void initMqtt();
void initOta();
void initWebServer();
void initInput();
void restorePreferences();
void updateRemoteControlInputs();
void updateControlLoop(uint32_t nowMs);
void processActiveControl(uint32_t nowMs);
void processInactiveControl(uint32_t nowMs);
void applyDriveOutputs(float pidAngleOutput, float steer);
void publishBatteryStatus(uint32_t nowMs);
void publishPlotData();
void parseSerial();
void parseCommand(const char* data, uint8_t length);
float mapFloat(float x, float inMin, float inMax, float outMin, float outMax);
void calculateGyroOffset(uint8_t nSample);
void readSensor();
void initSensor(uint8_t sampleCount);
void setMicroStep(uint8_t uStep);
void sendWifiList();
void initMqtt();
void mqttReconnect();
void publishRobotStatus();
void handleMqttMessage(char* topic, byte* payload, unsigned int length);
void handleIncomingCommand(const char* command);
const char* controlStateName();
const char* controlModeName();
void webSocketEvent(uint8_t num, WStype_t type, uint8_t * payload, size_t length);
void sendConfigurationData(uint8_t num);

#ifdef INPUT_PPM
volatile int32_t rxData[] = {0,0,0,0,0,0,0,0};
volatile uint32_t rxPre = 1;
volatile uint8_t channelNr = 0;
volatile uint8_t firstRoundCounter = 2;
volatile bool firstRoundPassed = false;
volatile bool validRxValues = false;

void rxFalling() {
  if (micros() - rxPre > 6000) {
    rxPre = micros();
    channelNr = 0;
    firstRoundCounter--;
    if (firstRoundCounter == 0) {
      firstRoundPassed = true;
    }
  } else {
    rxData[channelNr] = micros() - rxPre;
    rxPre = micros();
    channelNr++;
  }

  if (!validRxValues && firstRoundPassed) {
    validRxValues = true;
  }
}
#endif

void setup() {
  Serial.begin(115200);
  delay(50);

  echoChipInformation();

  Serial.println("setup: hardware");
  initHardware();
  Serial.println("setup: storage");
  initStorage();
  Serial.println("setup: imu");
  initImu();
  Serial.println("setup: preferences");
  restorePreferences();
  Serial.println("setup: network");
  initNetwork();
  Serial.println("setup: mqtt");
  initMqtt();
  Serial.println("setup: ota");
  initOta();
  Serial.println("setup: web server");
  initWebServer();
  Serial.println("setup: input");
  initInput();

#ifdef esp32_s3
  stepperDriverLeft.setHardwareEnablePin(kTmcEnablePinLeft);
  stepperDriverRight.setHardwareEnablePin(kTmcEnablePinRight);
  stepperDriverLeft.setup(tmcSerialStream, kTmcSerialBaudRateStep, TMC2209::SERIAL_ADDRESS_0, kTmcRxPin, kTmcTxPin);
  stepperDriverRight.setup(tmcSerialStream, kTmcSerialBaudRateStep, TMC2209::SERIAL_ADDRESS_1, kTmcRxPin, kTmcTxPin);
  stepperDriverLeft.enableAutomaticCurrentScaling();
  stepperDriverRight.enableAutomaticCurrentScaling();
  //stepperDriverLeft.enableAutomaticGradientAdaptation();
  //stepperDriverRight.enableAutomaticGradientAdaptation();
  setMicroStep(microStep);
  stepperDriverLeft.setRunCurrent(kTmcRunCurrent);
  stepperDriverRight.setRunCurrent(kTmcRunCurrent);
  pinMode(kPinFan, OUTPUT);
  digitalWrite(kPinFan, HIGH);
  if(stepperDriverLeft.isCommunicating() && stepperDriverRight.isCommunicating()) {
    Serial.println("stepperdrivers set up and communicating");
  } else {
    while(!stepperDriverLeft.isCommunicating() && !stepperDriverRight.isCommunicating()) {
      Serial.println("Stepper drivers not working, trying again");
      stepperDriverLeft.setup(tmcSerialStream, kTmcSerialBaudRateStep, TMC2209::SERIAL_ADDRESS_0, kTmcRxPin, kTmcTxPin);
      stepperDriverRight.setup(tmcSerialStream, kTmcSerialBaudRateStep, TMC2209::SERIAL_ADDRESS_1, kTmcRxPin, kTmcTxPin);
    }
  }
#endif

  motLeft.init();
  motRight.init();
  motLeft.microStep = microStep;
  motRight.microStep = microStep;

#ifdef esp32_s3
  stepperDriverLeft.enable();
  stepperDriverRight.enable();
#endif

#ifdef esp32_s3
  analogWrite(kPinMotorCurrent, motorCurrent);
#else
  dacWrite(kPinMotorCurrent, motorCurrent);
#endif
  // Initialize PID controllers. Angle PID uses preference-backed defaults loaded in restorePreferences().
  pidAngle.setParameters(pref_pid1_p, pref_pid1_i, pref_pid1_d, pref_pid1_m);
  pidPos.setParameters(1.0f, 0.0f, 1.2f, 50);
  pidSpeed.setParameters(6.0f, 5.0f, 0.0f, 20);

  Serial.println("Ready");

  esp_adc_cal_value_t adcType = esp_adc_cal_characterize(ADC_UNIT_1, ADC_ATTEN_0db, ADC_WIDTH_BIT_12, 1100, &adcChars);
  if (adcType == ESP_ADC_CAL_VAL_EFUSE_VREF) {
    Serial.println("eFuse Vref");
  } else if (adcType == ESP_ADC_CAL_VAL_EFUSE_TP) {
    Serial.println("Two Point");
  } else {
    Serial.println("Default");
  }

  Serial << "ADC calibration values (attenuation, vref, coeff a, coeff b): "
         << adcChars.atten << "\t" << adcChars.vref << "\t"
         << adcChars.coeff_a << "\t" << adcChars.coeff_b << endl;

  adc1_config_channel_atten(kBatteryAdcChannel, ADC_ATTEN_0db);
#ifndef esp32_s3
  adc_set_data_inv(ADC_UNIT_1, true);
#endif

  Serial.println("Booted, ready for driving!");
  digitalWrite(kPinLedRight, HIGH);
}

void loop() {
  if (!mqttClient.connected()) {
    mqttReconnect();
  }
  mqttClient.loop();

  static uint32_t lastControlUs = 0;
  uint32_t nowUs = micros();
  uint32_t nowMs = millis();

  if (nowUs - lastControlUs >= kControlPeriodUs) {
    lastControlUs = nowUs;
    readSensor();
    updateRemoteControlInputs();
    updateControlLoop(nowMs);
    motLeft.update();
    motRight.update();
    publishBatteryStatus(nowMs);
    publishPlotData();
    parseSerial();
    ArduinoOTA.handle();
#ifdef INPUT_IBUS
    IBus.loop();
#endif
    wsServer.loop();
#ifdef INPUT_PS3
#ifndef esp32_s3
    if (Ps3.isConnected()) {
      remoteControl.speed = -1.0f * Ps3.data.analog.stick.ly / 1.27f * remoteControl.speedGain + remoteControl.speedOffset;
      remoteControl.steer = Ps3.data.analog.stick.rx / 1.27f * remoteControl.steerGain;
    }
#endif
#endif

    if (nowMs - lastMqttPublishMs >= kMqttPublishIntervalMs) {
      lastMqttPublishMs = nowMs;
      publishRobotStatus();
    }
  }
}

void echoChipInformation() {
  // Print ESP32 chip information to serial console
  Serial.println("\n--- Connected ESP Chip Information ---");

  // Built-in Arduino core helper
  Serial.printf("Chip Model:        %s\n", ESP.getChipModel());
  Serial.printf("Chip Revision:     %d\n", ESP.getChipRevision());
  Serial.printf("CPU Frequency:     %d MHz\n", ESP.getCpuFreqMHz());
  Serial.printf("Flash Size:        %d MB\n", ESP.getFlashChipSize() / (1024 * 1024));
  
  // Unique MAC / Chip ID
  uint64_t chipid = ESP.getEfuseMac();
  Serial.printf("Unique MAC/ID:     %04X%08X\n", (uint16_t)(chipid>>32), (uint32_t)chipid);
  Serial.println("--------------------------------------\n");
}

void initHardware() {
#ifndef esp32_s3
  Serial.println("hardware: motor enable");
  pinMode(kPinMotorEnable, OUTPUT);
#endif
#ifndef esp32_s3
  Serial.println("hardware: microstep pins");
  pinMode(kPinMicroStep1, OUTPUT);
  pinMode(kPinMicroStep2, OUTPUT);
  pinMode(kPinMicroStep3, OUTPUT);
#endif
#ifndef esp32_s3
  Serial.println("hardware: motor enable high");
  digitalWrite(kPinMotorEnable, HIGH);
#endif
#ifndef esp32_s3
  Serial.println("hardware: set microstep");
#endif
  setMicroStep(microStep);

  Serial.println("hardware: leds");
  pinMode(kPinLed, OUTPUT);
  pinMode(kPinLedLeft, OUTPUT);
  pinMode(kPinLedRight, OUTPUT);
  digitalWrite(kPinLed, LOW);
  digitalWrite(kPinLedLeft, HIGH);
  digitalWrite(kPinLedRight, LOW);
}

void initStorage() {
  preferences.begin("settings", false);
  if (!SPIFFS.begin(kFormatSPIFFSIfFailed)) {
    Serial.println("SPIFFS mount failed");
  } else {
    Serial.println("SPIFFS mount success");
  }
}

void initImu() {
  delay(200);
#ifdef esp32_s3
  Wire.setPins(kImuSdaPin, kImuSclPin);
  Wire.begin(kImuSdaPin, kImuSclPin, 400000UL);
  Wire.setTimeOut(20);
  delay(100);
  if (imu.begin() != 0) {
    Serial.println("LSM6DS3 initialization failed");
    return;
  } else {
    Serial.println("LSM6DS3 initialized");
  }
  imuReady = true;
  Serial.printf("LSM6DS3 sample: ax=%.3f ay=%.3f az=%.3f gx=%.3f gy=%.3f gz=%.3f\n",
                imu.readFloatAccelX(), imu.readFloatAccelY(), imu.readFloatAccelZ(),
                imu.readFloatGyroX(), imu.readFloatGyroY(), imu.readFloatGyroZ());
#else
  Wire.begin(21, 22, 400000UL);
  delay(100);
  Serial.println(imu.testConnection());
  imu.initialize();
  imu.setFullScaleGyroRange(MPU6050_GYRO_FS_500);
#endif
  delay(50);
  initSensor(50);
}

void restorePreferences() {
  if (preferences.getUInt("pref_version", 0) != kPreferenceVersion) {
    preferences.clear();
    preferences.putUInt("pref_version", kPreferenceVersion);
    Serial << "EEPROM init complete, all preferences deleted, new pref_version: " << kPreferenceVersion << "\n";
  }

  for (uint8_t i = 0; i < 3; ++i) {
    char key[16];
    sprintf(key, "gyro_offset_%u", i);
    gyroOffset[i] = preferences.getShort(key, 0);
    Serial << gyroOffset[i] << "\t";
  }
  Serial << endl;

  angleOffset = preferences.getFloat("angle_offset", 0.0f);

  // Load stored PID angle controller parameters if present
  pref_pid1_p = preferences.getFloat("pid1_p", pref_pid1_p);
  pref_pid1_i = preferences.getFloat("pid1_i", pref_pid1_i);
  pref_pid1_d = preferences.getFloat("pid1_d", pref_pid1_d);
  pref_pid1_m = preferences.getFloat("pid1_m", pref_pid1_m);

  size_t nameLength = preferences.getBytes("robot_name", robotName, sizeof(robotName));
  if (nameLength == 0) {
    strncpy(robotName, kDefaultRobotName, sizeof(robotName));
    robotName[sizeof(robotName) - 1] = '\0';
  } else {
    robotName[min(nameLength, sizeof(robotName) - 1)] = '\0';
  }

  Serial.println(robotName);
}

void initNetwork() {
  bool wifiConnected = false;
  if (preferences.getUInt("wifi_mode", 0) == 1) {
    char ssid[63] = {0};
    char key[63] = {0};
    preferences.getBytes("wifi_ssid", ssid, sizeof(ssid));
    preferences.getBytes("wifi_key", key, sizeof(key));
    Serial << "Connecting to '" << ssid << "'" << endl;
    WiFi.mode(WIFI_STA);
    WiFi.begin(ssid, key);
    if (WiFi.waitForConnectResult(10000) == WL_CONNECTED) {
      Serial.print("Connected to WiFi with IP address: ");
      Serial.println(WiFi.localIP());
      wifiConnected = true;
    } else {
      Serial.println("Could not connect to known WiFi network");
    }
  }

  if (!wifiConnected) {
    Serial.println("Starting AP...");
    WiFi.mode(WIFI_AP_STA);
    WiFi.softAP(robotName, kWifiApPassword);
    Serial << "AP named '" << WiFi.softAPSSID() << "' started, IP address: " << WiFi.softAPIP() << endl;
  }

  Serial << "WiFi station MAC: " << WiFi.macAddress() << endl;
  Serial << "WiFi AP MAC: " << WiFi.softAPmacAddress() << endl;
}

void initMqtt() {
  mqttClient.setServer(kMqttBroker, kMqttPort);
  mqttClient.setCallback(handleMqttMessage);
  snprintf(mqttStatusTopic, sizeof(mqttStatusTopic), "robots/%s/status", robotName);
  snprintf(mqttCommandTopic, sizeof(mqttCommandTopic), "robots/%s/command", robotName);
}

void mqttReconnect() {
  static uint32_t lastMqttAttemptMs = 0;

  if (mqttClient.connected()) {
    return;
  }
  if (WiFi.status() != WL_CONNECTED) {
    return;
  }
  if (millis() - lastMqttAttemptMs < 2000) {
    return;
  }
  lastMqttAttemptMs = millis();

  Serial << "Connecting to MQTT broker " << kMqttBroker << ":" << kMqttPort << "..." << endl;
  if (mqttClient.connect(robotName)) {
    Serial.println("MQTT connected");
    mqttClient.subscribe(mqttCommandTopic);
    mqttClient.subscribe(kMqttAllCommandTopic);
  } else {
    Serial.print("MQTT connect failed, rc=");
    Serial.println(mqttClient.state());
  }
}

void publishRobotStatus() {
  if (!mqttClient.connected()) {
    return;
  }
  // Include PID angle controller parameters so external dashboards can initialize themselves
  char payload[512];
  snprintf(payload, sizeof(payload),
           "{\"name\":\"%s\",\"battery\":%.2f,\"angle\":%.2f,\"state\":\"%s\",\"mode\":\"%s\",\"c1p\":%.4f,\"c1i\":%.4f,\"c1d\":%.4f,\"c1m\":%.4f}",
           robotName,
           controlState.batteryVoltage,
           filterAngle,
           controlStateName(),
           controlModeName(),
           pidAngle.K,
           pidAngle.Ti,
           pidAngle.Td,
           pidAngle.maxOutput);
  mqttClient.publish(mqttStatusTopic, payload, true);
}
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

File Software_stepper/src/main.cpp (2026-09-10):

#include <TMC2209.h>

// This example will not work on Arduino boards without HardwareSerial ports,
// such as the Uno, Nano, and Mini.
//
// See this reference for more details:
// https://www.arduino.cc/reference/en/language/functions/communication/serial/

HardwareSerial & serial_stream = Serial1;

const int RX_PIN = 18;
const int TX_PIN = 17;
const int L_STEP_PIN = 11;
const int R_STEP_PIN = 14;
const int L_DIR_PIN = 10;
const int R_DIR_PIN = 13;
const int L_EN_PIN = 9;
const int R_EN_PIN = 12;

const long SERIAL_BAUD_RATE = 115200;
const int DELAY = 3000;

// Instantiate TMC2209
TMC2209 stepper_driver_0;
TMC2209 stepper_driver_1;

void setup()
{
  Serial.begin(SERIAL_BAUD_RATE);

  pinMode(L_STEP_PIN, OUTPUT);
  pinMode(R_STEP_PIN, OUTPUT);
  pinMode(L_DIR_PIN, OUTPUT);
  pinMode(R_DIR_PIN, OUTPUT);

  stepper_driver_0.setup(serial_stream, SERIAL_BAUD_RATE, TMC2209::SERIAL_ADDRESS_0, RX_PIN, TX_PIN);
  stepper_driver_1.setup(serial_stream, SERIAL_BAUD_RATE, TMC2209::SERIAL_ADDRESS_1, RX_PIN, TX_PIN);
  stepper_driver_0.setHardwareEnablePin(L_EN_PIN);
  stepper_driver_1.setHardwareEnablePin(R_EN_PIN);
  stepper_driver_0.enableAutomaticCurrentScaling();
  stepper_driver_1.enableAutomaticCurrentScaling();
  stepper_driver_0.setRunCurrent(20);
  stepper_driver_1.setRunCurrent(20);
  stepper_driver_0.setMicrostepsPerStep(8);
  stepper_driver_1.setMicrostepsPerStep(8);
  stepper_driver_0.disable();
  stepper_driver_1.disable();
  if(!stepper_driver_0.isSetupAndCommunicating()) {
    Serial.println("Trying connection to stepper driver 0 again");
    stepper_driver_0.setup(serial_stream, SERIAL_BAUD_RATE, TMC2209::SERIAL_ADDRESS_0, RX_PIN, TX_PIN);
    delay(100);
  }
  if(!stepper_driver_1.isSetupAndCommunicating()) {
    Serial.println("Trying connection to stepper driver 1 again");
    stepper_driver_1.setup(serial_stream, SERIAL_BAUD_RATE, TMC2209::SERIAL_ADDRESS_1, RX_PIN, TX_PIN);
    delay(100);
  }
}

void loop()
{
  if (stepper_driver_0.isSetupAndCommunicating() && stepper_driver_1.isSetupAndCommunicating())
  {
    Serial.println("Stepper drivers 0 and 1 are setup and communicating!");
    Serial.println("Try turning driver power off to see what happens.");
  }
  else if (stepper_driver_0.isCommunicatingButNotSetup())
  {
    Serial.println("Stepper driver 0 is communicating but not setup!");
    Serial.println("Running setup again...");
    stepper_driver_0.setup(serial_stream);
  }
  else if (stepper_driver_1.isCommunicatingButNotSetup())
  {
    Serial.println("Stepper driver 1 is communicating but not setup!");
    Serial.println("Running setup again...");
    stepper_driver_1.setup(serial_stream);
  }
  else
  {
    Serial.println("Stepper driver is not communicating!");
    Serial.println("Try turning driver power on to see what happens.");
  }
  Serial.println();
  delay(DELAY);

  stepper_driver_0.enable();
  stepper_driver_1.enable();
  for(int i = 0; i < 2; i++) {
    if(i < 1) {
      digitalWrite(L_DIR_PIN, LOW);
      digitalWrite(R_DIR_PIN, LOW);
    }
    else {
      digitalWrite(L_DIR_PIN, HIGH);
      digitalWrite(R_DIR_PIN, HIGH);
    }
    for(int j = 0; j < 400; j++) {
      int step = j % 2;
      digitalWrite(L_STEP_PIN, j%2);
      digitalWrite(R_STEP_PIN, j%2);
      //Serial.print(">Step:"); Serial.print(step); Serial.print(", J:"); Serial.println(j);
      delay(5);
    }
  }


  Serial.println("*************************");
  Serial.println("getStatus()");
  TMC2209::Status status = stepper_driver_1.getStatus();
  Serial.print("status.over_temperature_warning = ");
  Serial.println(status.over_temperature_warning);
  Serial.print("status.over_temperature_shutdown = ");
  Serial.println(status.over_temperature_shutdown);
  Serial.print("status.short_to_ground_a = ");
  Serial.println(status.short_to_ground_a);
  Serial.print("status.short_to_ground_b = ");
  Serial.println(status.short_to_ground_b);
  Serial.print("status.low_side_short_a = ");
  Serial.println(status.low_side_short_a);
  Serial.print("status.low_side_short_b = ");
  Serial.println(status.low_side_short_b);
  Serial.print("status.open_load_a = ");
  Serial.println(status.open_load_a);
  Serial.print("status.open_load_b = ");
  Serial.println(status.open_load_b);
  Serial.print("status.over_temperature_120c = ");
  Serial.println(status.over_temperature_120c);
  Serial.print("status.over_temperature_143c = ");
  Serial.println(status.over_temperature_143c);
  Serial.print("status.over_temperature_150c = ");
  Serial.println(status.over_temperature_150c);
  Serial.print("status.over_temperature_157c = ");
  Serial.println(status.over_temperature_157c);
  Serial.print("status.current_scaling = ");
  Serial.println(status.current_scaling);
  Serial.print("status.stealth_chop_mode = ");
  Serial.println(status.stealth_chop_mode);
  Serial.print("status.standstill = ");
  Serial.println(status.standstill);
  Serial.println("*************************");
  Serial.println();

  Serial.println();

  stepper_driver_0.disable();
  stepper_driver_1.disable();
}

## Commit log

2026-07-08 Start of PCB
    [Balancing_cam.kicad_pcb, Balancing_cam.kicad_sch, IMU.kicad_sch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]
2026-07-10 Started with more stuff tho battery chargeis wip
    [Balancing_cam.kicad_sch, IMU.kicad_sch, Microcontroller.kicad_sch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]
2026-08-09 Finalized schematic and pcb
    [Balancing_cam.kicad_pcb, Balancing_cam.kicad_sch, Breakout.kicad_sch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]
2026-08-10 Done, and completed bom
    [Balancing_cam.csv, Balancing_cam.kicad_pcb, Balancing_cam.kicad_sch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]
2026-08-10 Fixed DRC errors
    [Balancing_cam.kicad_pcb]
2026-08-10 Fixed Bom and added more GND fill
    [Balancing_cam.csv, Balancing_cam.kicad_pcb, IMU.kicad_sch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]
2026-08-11 Fixed small errors and routing issues
    [Balancing_cam.kicad_pcb]
2026-08-13 Fixed traces on the pcb
    [Balancing_cam.kicad_pcb]
2026-08-13 Update README with project details and specifications
    Added project description, PCB details, and specifications.
2026-08-13 Added blender render
    [Balancing_cam.blend, Balancing_cam.kicad_sch, IMU.kicad_sch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]
2026-09-02 Added bom and panelization
    [Balancing_cam_panel.kicad_pcb, bom.csv, designators.csv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]
2026-09-10 Added software and got it working
    [Balancing_cam.kicad_pcb, Balancing_cam.step, partition_no_ota.csv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]
